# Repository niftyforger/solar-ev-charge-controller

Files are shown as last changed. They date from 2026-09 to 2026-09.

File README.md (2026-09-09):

# Solar EV Charge Controller

Diverts surplus rooftop solar into EV charging by dynamically limiting the charge current a "dumb" (non-networked) EVSE offers to the car, based on real-time export data from a Sungrow hybrid inverter. The EVSE has no API or Modbus control path, so the only lever available is intercepting its Control Pilot (CP) signal to the car and clipping the duty cycle down when there isn't enough solar surplus to support the current it would otherwise offer.

> **⚠️ Safety & Disclaimer**
> This project modifies wiring in a vehicle charging circuit, adjacent to mains-connected equipment. Incorrect wiring or assembly can cause electric shock, fire, or damage to your vehicle or EVSE. It is not a certified product, has not been evaluated by any safety body, and may void your EVSE's warranty. Build and use it entirely at your own risk — see the [Safety model](#safety-model) section below for the fail-safe design rationale, and the [LICENSE](LICENSE) for the "AS IS" warranty disclaimer.

For full pin assignments, register maps, timing/ISR design detail, and the fail-safe rationale, see [CLAUDE.md](CLAUDE.md).

## How it works

A single ESP32-S3 splits the job across its two cores: Core 0 polls the inverter over WiFi and decides a target amps — a ceiling offered via CP, not what the car necessarily draws; Core 1 runs the real-time loop that actually shapes the CP waveform between the charger and the car. The two talk over a small queue/mutex bridge — Core 1 never blocks on anything Core 0-side.

```mermaid
flowchart LR
    subgraph inv["Sungrow SH8.0RS"]
        meter["DTSU666-20 meter\n(RS485, internal)"]
        winet["WiNet-S\nModbus TCP :502"]
    end

    subgraph esp["ESP32-S3"]
        direction TB
        core0["Core 0\nWiFi + Modbus poll\nsettling control law\nBLE config · OTA · control page"]
        bridge[["shared_state\nqueue + mutex"]]
        core1["Core 1\nGPIO edge ISR + HW timer\n-> RMT clamp waveform"]
        core0 -- "target amps" --> bridge --> core1
    end

    subgraph cp["CP interceptor board"]
        sense["opto-isolated\nsense out"]
        clamp["clamp MOSFET\n(shunts CP_LINE toward GND only)"]
        relay["disconnect relay\n(NC, series on CP_LINE)"]
    end

    ble["BLE config client\n(phone/laptop)"]

    winet <-->|"Modbus TCP\nregister 13009"| core0
    meter --- winet
    ble <-->|"WiFi SSID/password,\ninverter IP, device IP"| core0
    core1 -->|"opto-isolated\ndrive"| clamp
    core1 -->|"opto-isolated\ndrive"| relay
    sense -->|"opto-isolated"| core1

    evse["EVSE\n(native CP driver)"] == "CP_LINE" ==> tap(("•"))
    tap == "CP_LINE" ==> relay
    relay == "CP_LINE, opens to isolate\nthe vehicle on demand" ==> vehicle["Vehicle"]
    tap -.->|"tap"| sense
    clamp -.->|"tap"| tap
```

Key properties baked into the topology, not just firmware:
- **`CP_LINE` runs straight through from the EVSE to the vehicle connector, only ever interrupted by the disconnect relay.** The interceptor board taps onto it at one point (upstream of the relay) to sense it and, when needed, shunt it low — the sense/clamp tap is never wired inline, so removing or failing the board there can't interrupt the wire itself. The relay is the one deliberate exception: it's wired inline, in series, specifically so it *can* interrupt the wire — see [Safety model](#safety-model) for why that's still fail-safe.
- The clamp can only **shunt `CP_LINE` toward `GND`** — it has no way to source voltage, so it can clip current down but can never raise it above what the EVSE natively offers, regardless of what firmware does.
- The relay only ever **removes the vehicle's CP termination**, never alters the waveform — with it open, the EVSE sees the same thing it would see on a real unplug (state A) and stops offering charge using its own normal handling, not a signal this project invents.
- Isolation is **signal-only**: the sense/clamp/relay lines that cross into/out of Core 1 each go through their own optocoupler, but the sense/clamp/relay circuitry itself shares a ground with the ESP32 side (no separate PE-referenced supply). See [CP interceptor circuit](#cp-interceptor-circuit) below.
- **Home-battery discharge doesn't count as surplus.** The meter sits downstream of the home battery, so it can't tell fresh PV export apart from battery-discharge export on its own — Core 0 reads the inverter's battery-power register separately and subtracts any discharge back out before computing how much current the surplus can support, so the loop never diverts battery power into EV charging.

See [Safety model](#safety-model) below for the full fail-safe contract.

## CP interceptor circuit

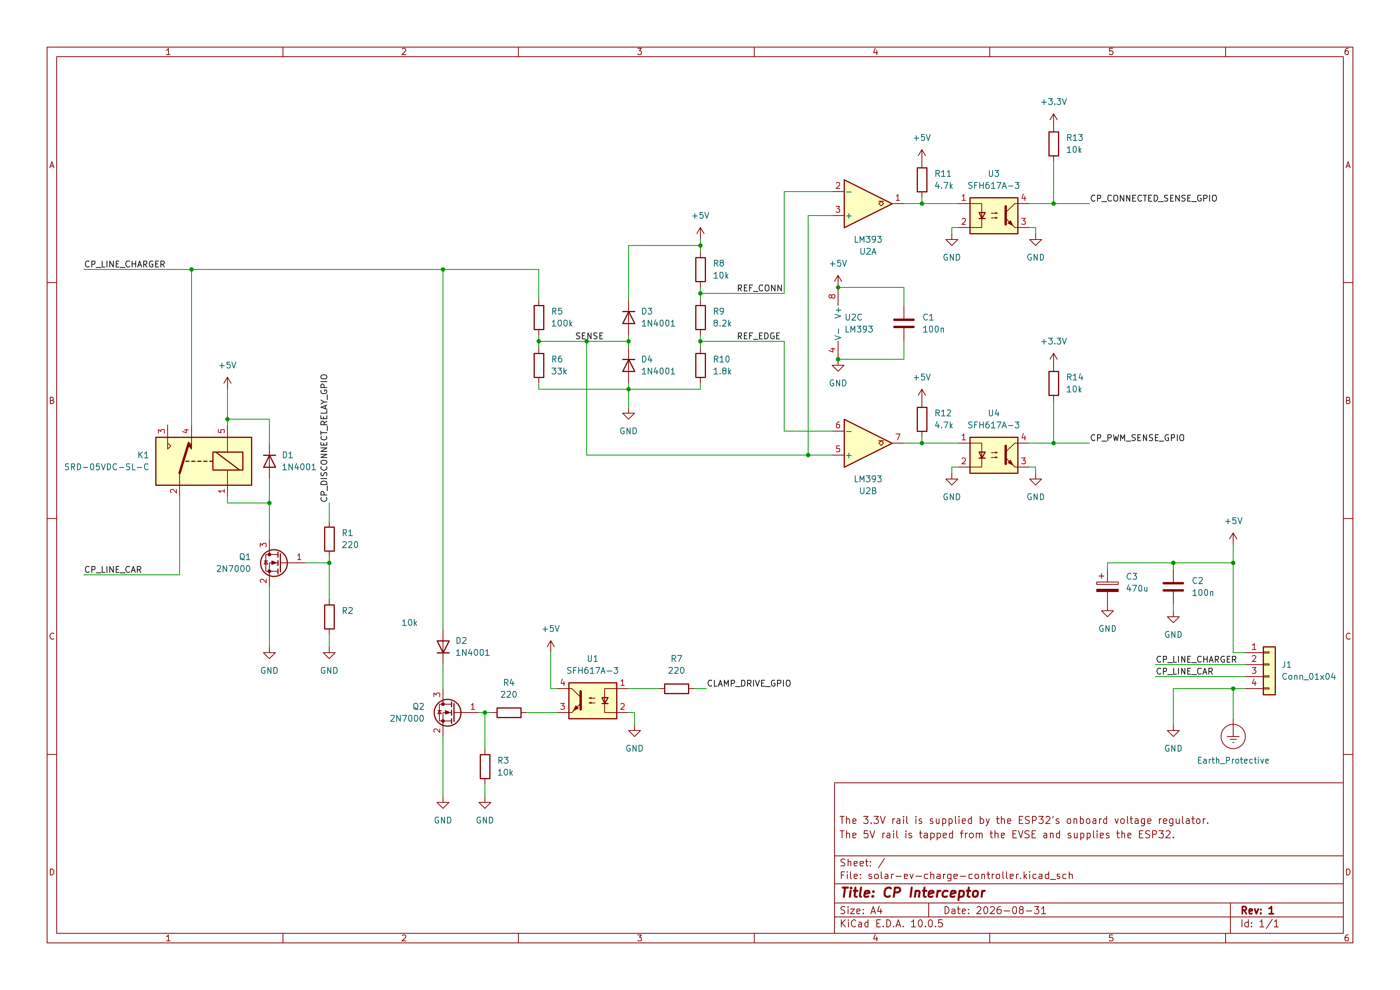
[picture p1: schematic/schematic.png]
CP interceptor schematic


KiCad source: [`schematic/solar-ev-charge-controller/`](schematic/solar-ev-charge-controller/).

`CP_LINE` feeds a high-Z divider (`R5`/`R6`) down to a `SENSE` node, read by a dual comparator (`U2`, LM393) against two fixed reference taps — one output detects vehicle-connected state (`CONNECTED_IN`), the other detects PWM edge activity (`EDGE_IN`). Each comparator output, plus the clamp drive command going the other way, crosses into the ESP32's domain through its own optocoupler (`U3`/`U4`/`U1` respectively) — that's the only isolation boundary; the sense/comparator/clamp circuitry otherwise shares `GND`/`+5V` with the ESP32 side. The clamp itself is a MOSFET (`Q2`, 2N7000) that taps onto `CP_LINE` through a series blocking diode (`D2`) and shunts it toward `GND` when driven; its gate defaults low via a pull-down resistor (`R3`) whenever nothing is actively driving it.

Further downstream (toward the vehicle) of the `R5`/`D2` tap sits a normally-closed disconnect relay (`K1`), wired in series on `CP_LINE` itself rather than tapped off it — the one deliberate break in an otherwise continuous wire. Its coil is driven through its own optocoupler and a low-side driver transistor (`Q1`), with a flyback diode (`D1`) across the coil. De-energized (the default whenever nothing is actively driving it) the contact stays closed and `CP_LINE` passes straight through; energizing it opens the contact and isolates the vehicle's CP termination from everything upstream, which the EVSE reads as a real unplug.

**Reference designators were renumbered by a KiCad annotation pass; the table below reflects the current schematic, wire-traced pin-by-pin to confirm.**

| Ref | Part | Note |
|---|---|---|
| `R5` / `R6` | 100kΩ / 33kΩ | `CP_LINE` → `SENSE` divider |
| `D3` / `D4` | 1N4001 | `SENSE` overvoltage clamp to `+5V` / `GND` |
| `R8` / `R9` / `R10` | 10k / 8.2k / 1.8k | reference ladder off `+5V` (REF_CONN ≈2.5V, REF_EDGE ≈0.45V) |
| `U2` | LM393 | dual comparator — unit 1 → `CONNECTED_IN` chain, unit 2 → `EDGE_IN` chain |
| `R11` / `R12` | 4.7kΩ | comparator unit 1/2 output pull-up to `+5V`, doubles as opto LED drive |
| `U3` / `U4` | SFH617A-3 | `CONNECTED_IN` / `EDGE_IN` optocouplers |
| `R13` / `R14` | 10kΩ | `CONNECTED_IN` / `EDGE_IN` pull-up to `+3.3V` (opto secondary) |
| `R7` | 220Ω | `CLAMP_DRIVE` opto (`U1`) LED current limit |
| `U1` | SFH617A-3 | `CLAMP_DRIVE` optocoupler |
| `R4` | 220Ω | opto secondary → `Q2` gate series resistor |
| `R3` | 10kΩ | `Q2` gate pull-down (default off) |
| `Q2` | 2N7000 | clamp MOSFET |
| `D2` | 1N4001 | series blocking diode, `CP_LINE` → `Q2` |
| `K1` | 5V SPDT signal relay (NC contact used) | disconnect relay, in series on `CP_LINE` downstream of the `R5`/`D2` tap |
| `Q1` | 2N7000 | `K1` coil low-side driver transistor |
| `D1` | 1N4001 | `K1` coil flyback diode |

Values are a starting point, not final — see [CLAUDE.md § CP interception circuit](CLAUDE.md#cp-interception-circuit) for the full rationale and [§ Open questions](CLAUDE.md#open-questions-for-implementation) for what's still unverified on the bench.

## Hardware

Freenove ESP32-S3-WROOM on its breakout board. Dual-core split:

| Core | Role |
|---|---|
| Core 0 | WiFi, Modbus TCP polling of the inverter, control law, BLE config server, OTA, control page |
| Core 1 (pinned, high priority) | GPIO edge-triggered ISR + hardware timer + RMT — asserts/releases the CP clamp with sub-task-switch latency |

Pin assignments live in [`include/config.h`](include/config.h) (see CLAUDE.md for the full table and rationale) — physically confirmed on the bench.

## Firmware layout

| File | Responsibility |
|---|---|
| [`src/main.cpp`](src/main.cpp) | Task/core setup |
| [`src/solar_control.*`](src/solar_control.cpp) | Core 0: WiFi, poll loop, settling control law, OTA, control page |
| [`src/modbus_tcp_client.*`](src/modbus_tcp_client.cpp) | Minimal hand-rolled Modbus TCP client for the WiNet-S |
| [`src/cp_interceptor.*`](src/cp_interceptor.cpp) | Core 1: edge capture, RMT clamp waveform, `BYPASS`/`ACTIVE` × `OSCILLATING`/`STANDBY` state machine, watchdog |
| [`src/shared_state.*`](src/shared_state.cpp) | Core0↔Core1 bridge (queue + mutex, zero-timeout on Core 1's side); also holds the BLE-provisioned WiFi/inverter-IP `RuntimeConfig` |
| [`src/ble_config.*`](src/ble_config.cpp) | Core 0: BLE server for provisioning WiFi SSID/password, inverter IP, and the BLE-config/control-page passwords, and reading back the device's current IP |
| [`include/config.h`](include/config.h) | Pins, control-loop constants, thresholds |
| [`include/secrets.h`](include/secrets.h) (gitignored) | `OTA_PASSWORD` only, used solely for OTA flashing — auto-generated from `.env` before every build, see below |

## Building & flashing

PlatformIO project, environment `freenove_esp32_s3_wroom`, framework Arduino.

```sh
cp .env.example .env   # then edit with a real OTA password
pio run                # build - regenerates include/secrets.h from .env first
pio run -t upload      # flash over USB
```

`include/secrets.h` is auto-generated from `OTA_PASSWORD` in `.env` by [`tools/sync_secrets.py`](tools/sync_secrets.py) (wired in as a PlatformIO pre-build step, so it runs for any env, any invocation path, including the VSCode PlatformIO IDE buttons) — don't edit it by hand, edit `.env` instead. WiFi SSID/password, the inverter IP, and the BLE-config/control-page passwords have no compile-time fallback — `OTA_PASSWORD` is used solely for OTA flashing. Everything else is provisioned over Bluetooth Low Energy after first flash. Connect with any BLE serial-terminal app (Serial Bluetooth Terminal, nRF Connect's UART plugin, etc.) — it auto-detects the device as a Nordic UART Service and drops straight into terminal mode — then send `AUTH <anything>` (open until a `BLE_PASS` is set), `SET WIFI_SSID <ssid>`, `SET WIFI_PASS <password>`, `SET INVERTER_IP <inverter ip>`, `COMMIT`, `SET BLE_PASS <password>` (required for `AUTH` on future connections), and `SET WEB_PASS <password>` (required before the HTTP control page below will respond to anything but a 403) — send `HELP` any time for the full command list. See [CLAUDE.md § BLE configuration](CLAUDE.md#ble-configuration) for the full protocol.

BLE advertises **indefinitely** until the device has been provisioned at least once, so a freshly-flashed board is always reachable — after that first `COMMIT`, it only advertises for `BLE_ADVERTISE_WINDOW_MS` (5 minutes, [`include/config.h`](include/config.h)) after each boot, closing the window for the rest of that session. To reconfigure a device that's already provisioned, power-cycle it and connect within that 5-minute window.

Once WiFi is up, subsequent flashes can go over OTA (`ArduinoOTA`, password-protected by `OTA_PASSWORD`) instead of pulling the board for USB access. Run it with `python tools/ota_upload.py` (loads `.env`'s `UPLOAD_PORT`/`OTA_PASSWORD` for that one invocation), or run `python tools/sync_env_vars.py` once and restart VSCode to make the PlatformIO IDE's own "Upload" button work directly with the `ota` environment selected — see the `[env:ota]` comment in [`platformio.ini`](platformio.ini) for why `.env` can't be wired in more automatically than that. The control page at `http://<device-ip>/` (HTTP Basic Auth, username `admin`, password set over BLE via `SET WEB_PASS` — refuses all requests until one has been set) is the same page used for live operation, with a grid-source dropdown to switch between the real inverter and a family of reactive simulated scenarios (no sun / low / moderate / high / battery-discharge) — the latter exercise the full poll/control-law/target-amps path for bench and night-time testing without real solar.

## Safety model

- **Inherent (topology-level):** no drive on `CLAMP_DRIVE` (idle, unpowered, firmware not yet running) → a pull-down resistor holds the clamp MOSFET's gate low → native pass-through, unconditionally. Clamp stuck on/shorted → CP read as a fault/disconnect by the EVSE → charging stops, doesn't misbehave. The clamp can never drive current *above* native regardless of firmware state, since it can only shunt the line toward `GND`, never source voltage onto it. The disconnect relay (`K1`) follows the same direction: no drive on its coil → normally-closed contact stays closed → `CP_LINE` passes through unconditionally. Losing the ESP32 must never leave the vehicle unable to charge at all.
- **Explicit (firmware-level):** if Core 0 can't get a fresh inverter reading for ~60s, Core 1 switches to `MODE_BYPASS`, stops scheduling clamp assertions, and keeps the disconnect relay closed regardless of duty state — same end state as a power loss. A data fault is never treated as a confident "no surplus" decision, so it never triggers a disconnect. A hardware watchdog on the CP task forces a reboot rather than letting a hang freeze the waveform mid-cycle.
- **When surplus is genuinely below the 6A floor** (fresh data, not a fault): Core 1 opens `K1`, isolating the vehicle's CP termination so the EVSE reads a real unplug and stops charging via its own handling — this *is* a relay-backed physical disconnect, and deliberately replaced an earlier version that instead released the clamp to full native current at exactly the moment surplus was lowest. See [CLAUDE.md § CP interception circuit](CLAUDE.md#cp-interception-circuit) for the full rationale.

## Status

Bench-tested through all stages, including the real EVSE and a real vehicle (2026-09-04): BLE provisioning, comparator thresholds, disconnect-relay open/close, and live mid-charge duty-cycle changes all confirmed clean. All previously open items are now resolved — see [CLAUDE.md § Open questions](CLAUDE.md#open-questions-for-implementation).

## Gallery

Control page:

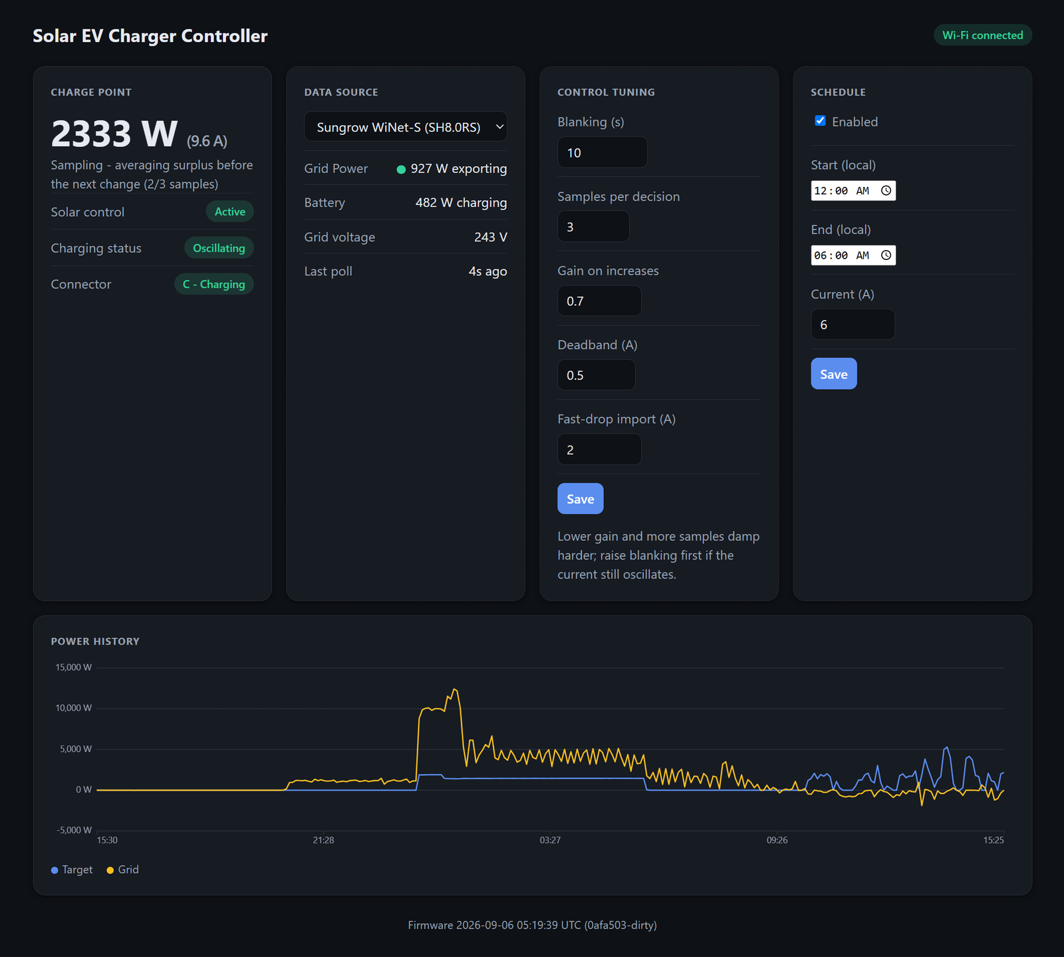
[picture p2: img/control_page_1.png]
Control page 1


Bench setup:

| | |
|---|---|
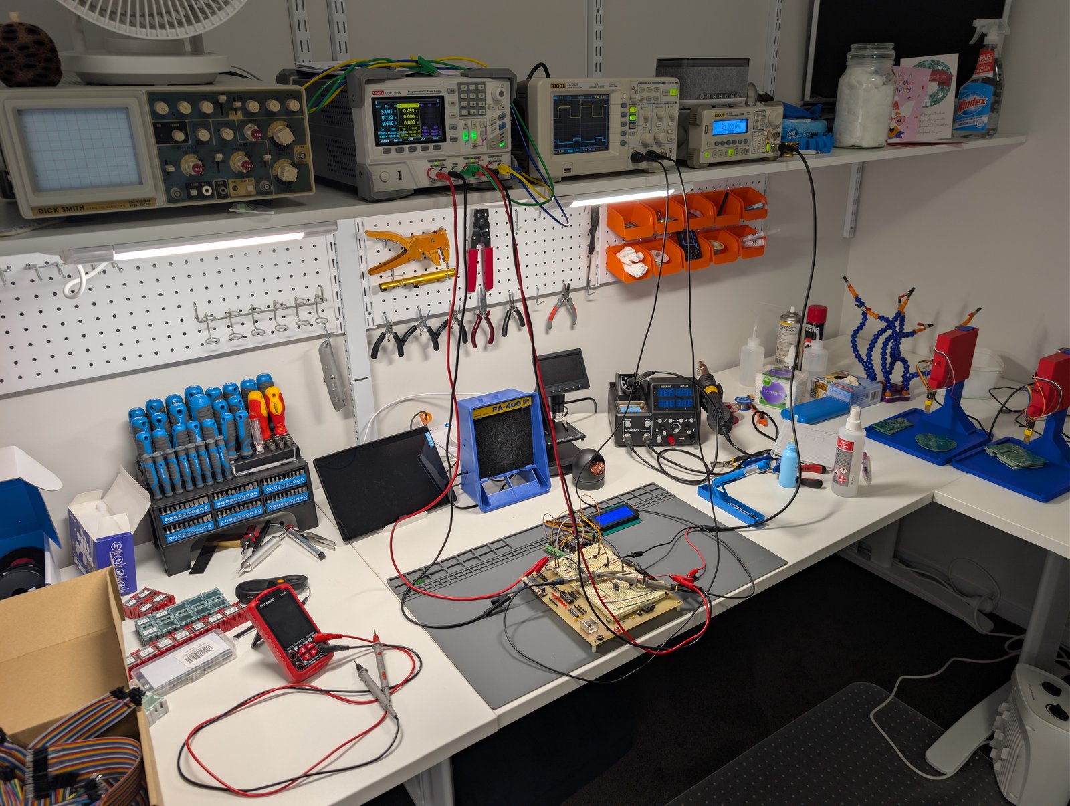
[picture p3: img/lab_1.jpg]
Bench setup 1
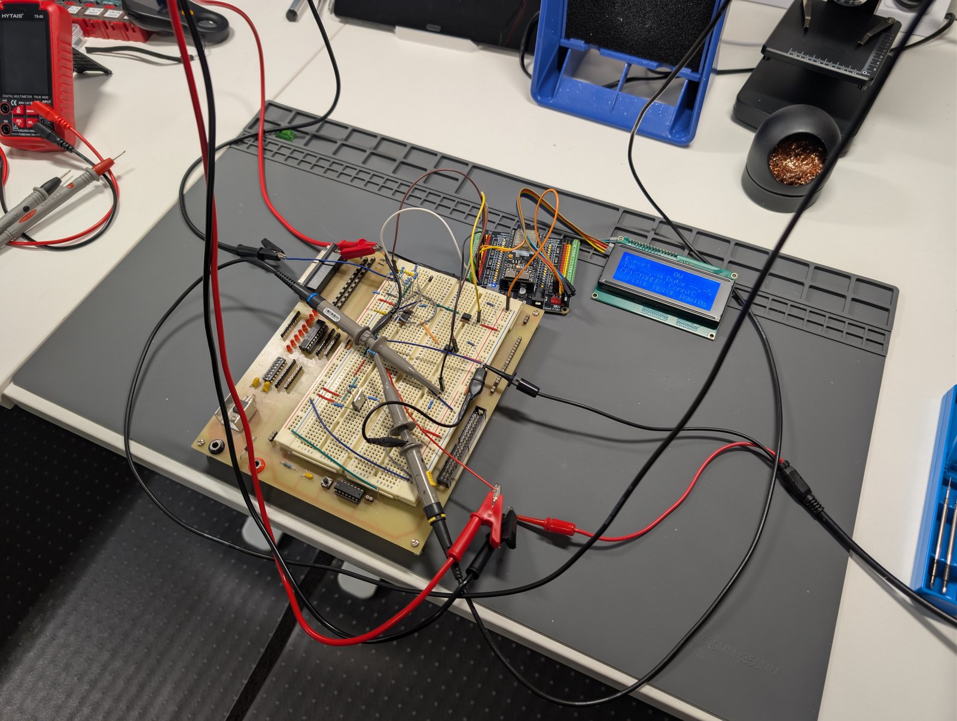
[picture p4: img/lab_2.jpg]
Bench setup 2
|  |  |
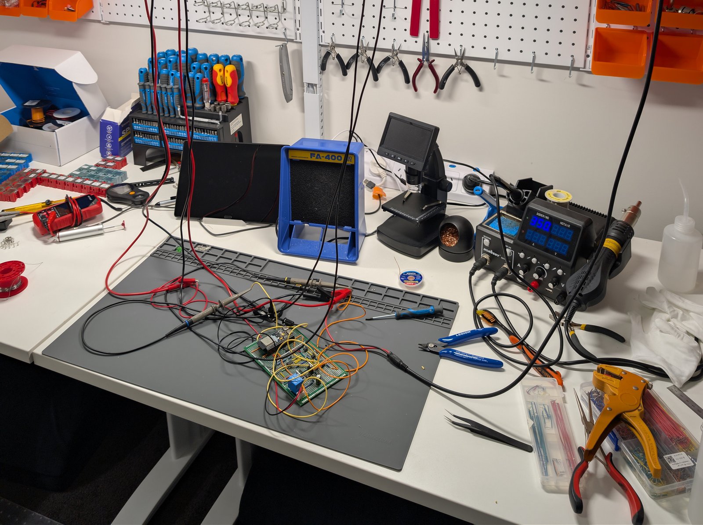
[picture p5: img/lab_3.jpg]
Bench setup 3
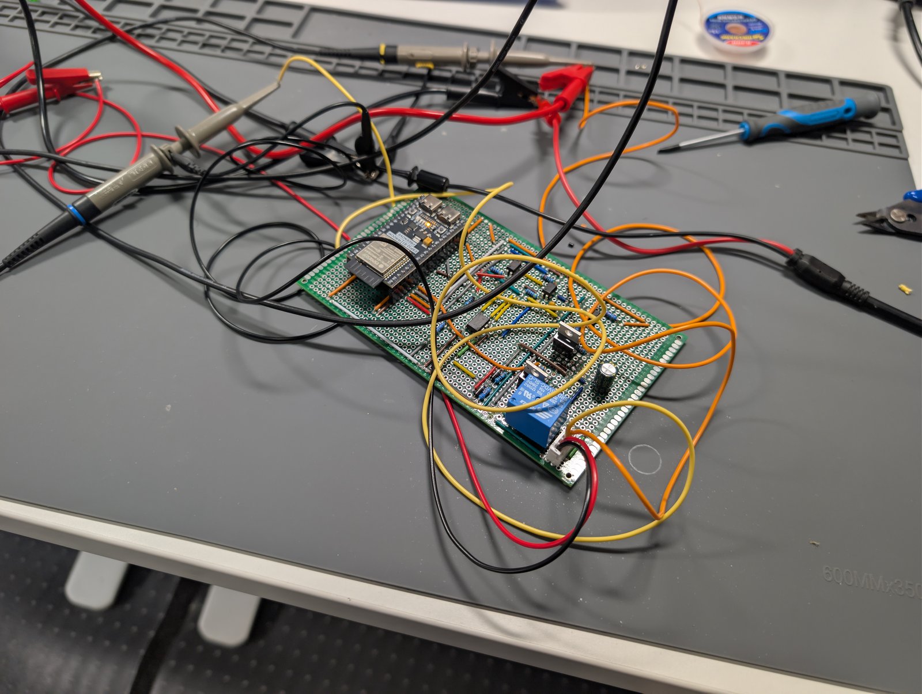
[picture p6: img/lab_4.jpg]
Bench setup 4
|  |  |

EVSE enclosure:

| | |
|---|---|
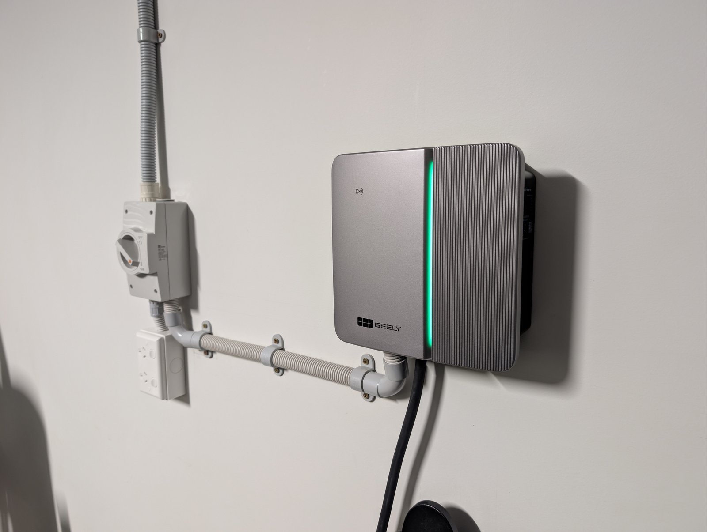
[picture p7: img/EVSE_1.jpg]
Control board installed inside the EVSE enclosure
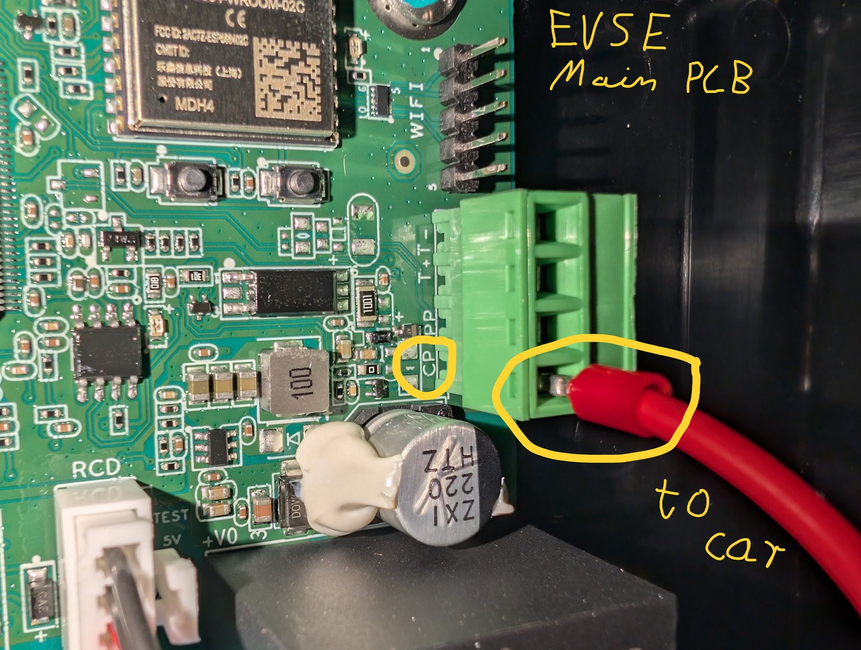
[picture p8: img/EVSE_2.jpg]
Control board installed inside the EVSE enclosure
|  |  |
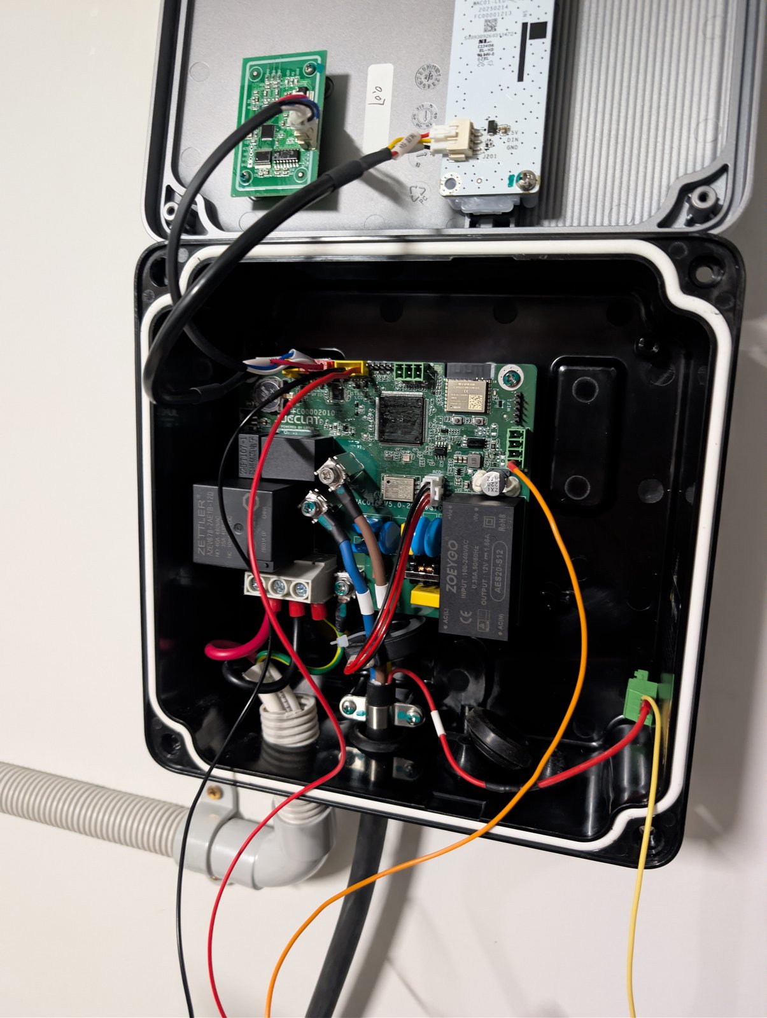
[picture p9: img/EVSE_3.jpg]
Control board installed inside the EVSE enclosure
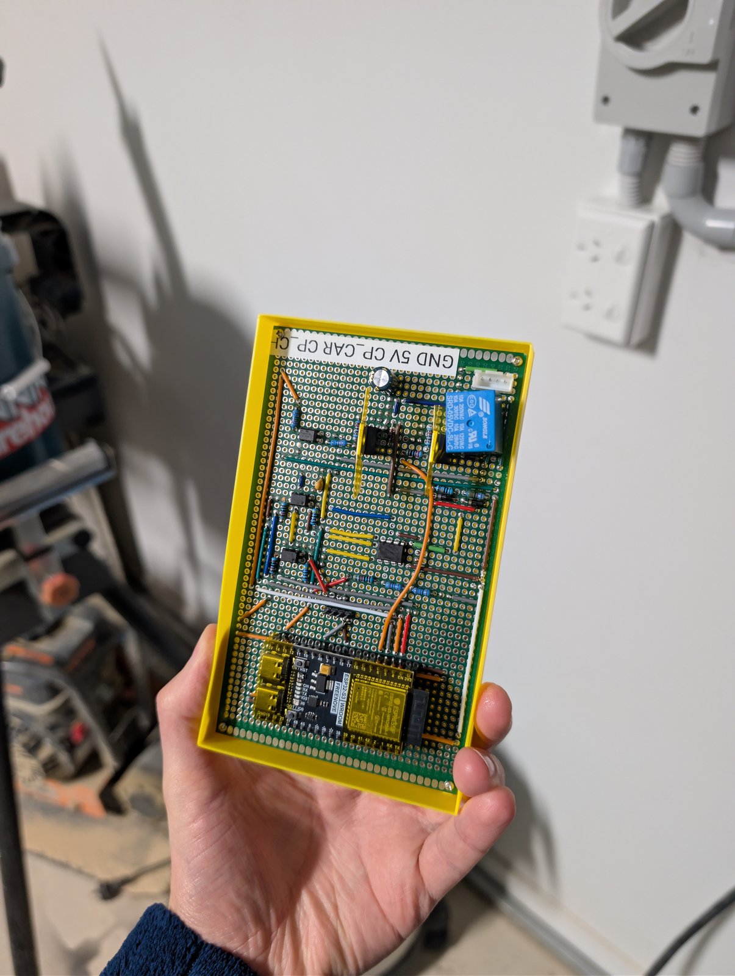
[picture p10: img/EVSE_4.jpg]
Interceptor board in its 3D-printed enclosure
|  |  |
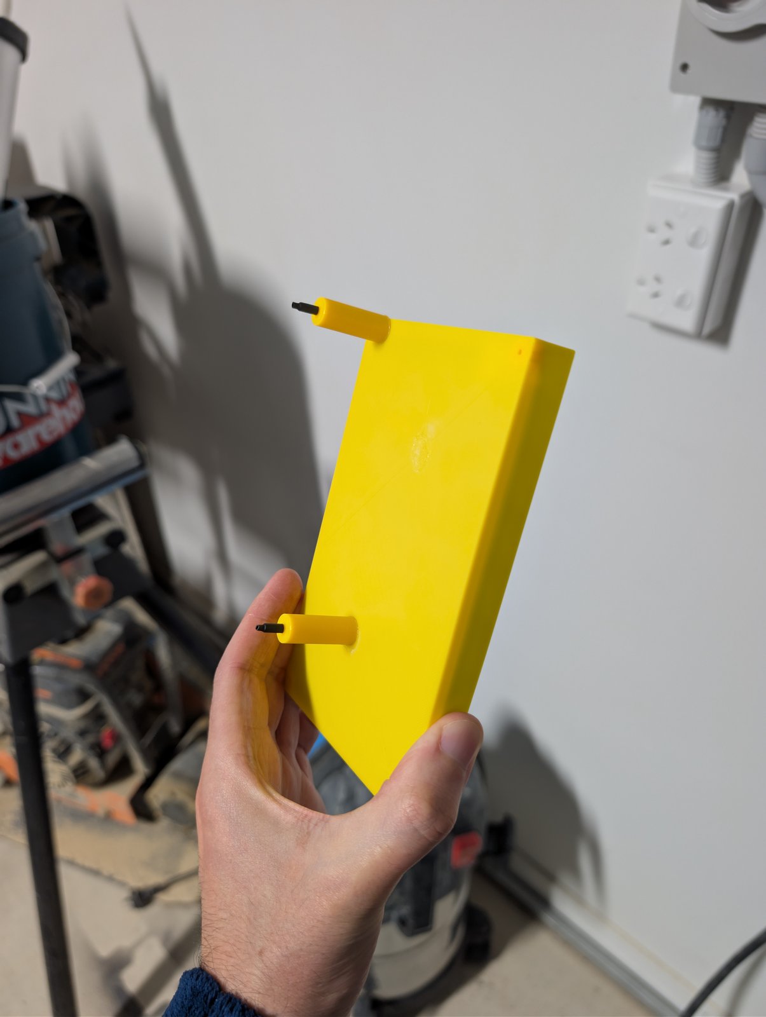
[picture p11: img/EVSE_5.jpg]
Interceptor enclosure, closed
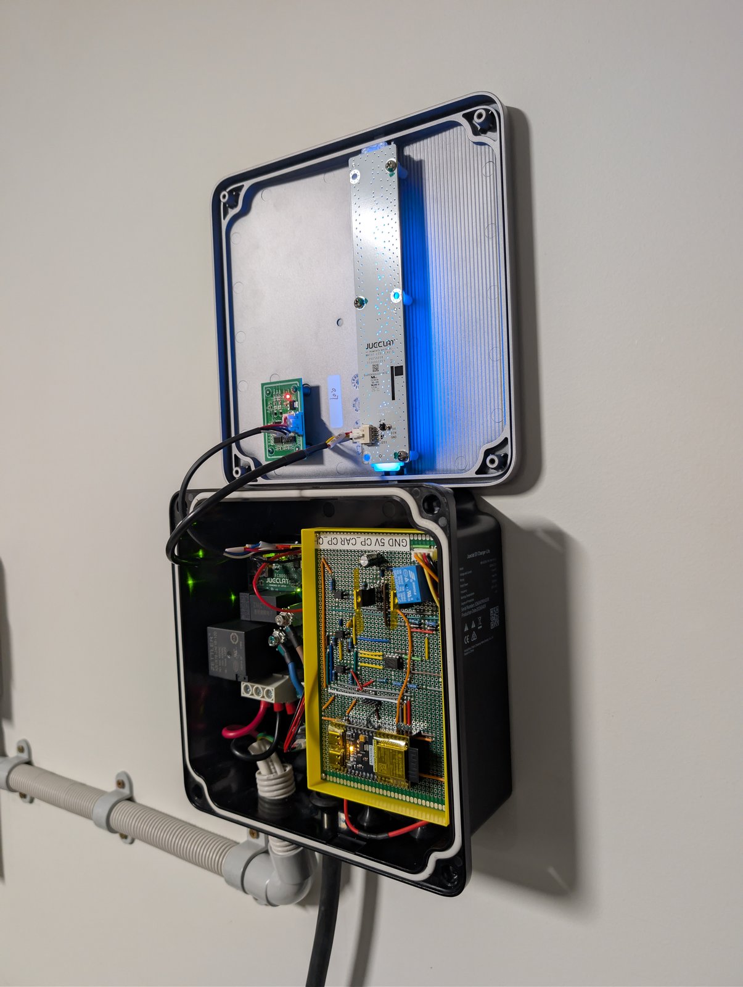
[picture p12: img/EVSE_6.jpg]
Interceptor board mounted inside the powered-on EVSE
|  |  |

## Author

[coder@niftyforger.com](mailto:coder@niftyforger.com)

Need a better way to organize your inventory, assemblies and projects? Try [niftyforger.com](https://niftyforger.com)

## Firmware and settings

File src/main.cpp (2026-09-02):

#include <Arduino.h>
#include "config.h"
#include "shared_state.h"
#include "solar_control.h"
#include "ble_config.h"
#include "cp_interceptor.h"

void setup() {
    Serial.begin(115200);

    shared_state_init();

    // BLE config server: independent of WiFi state, must come up even on a
    // fully unprovisioned board - see ble_config.cpp.
    ble_config_init();

    // Core 1: real-time CP interception, pinned + highest priority.
    xTaskCreatePinnedToCore(cp_interceptor_task, "cp_interceptor", 8192,
                             nullptr, TASK_PRIO_CP, nullptr, CORE_CP);

    // Core 0: WiFi/Modbus control loop.
    xTaskCreatePinnedToCore(solar_control_task, "solar_control", 8192,
                             nullptr, TASK_PRIO_SOLAR, nullptr, CORE_SOLAR);
}

void loop() {
    vTaskDelete(NULL);
}

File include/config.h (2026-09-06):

#pragma once

#include <stdint.h>

// Pin assignments. ESP32-S3: ADC1 = GPIO1-10 (ADC2 shares hardware with WiFi, avoid it).
// Strapping pins (0, 3, 45, 46) and USB-JTAG pins (19, 20) are avoided.

// CP sense input (post opto-isolator, digital 0/3.3V square wave)
#define CP_PWM_SENSE_GPIO      5

// CP clamp drive output -> optocoupler -> MOSFET gate driver (RMT TX)
#define CLAMP_DRIVE_GPIO       6

// CP connector-state sense, CONNECTED_IN (post opto) - see CLAUDE.md "CP interception circuit"
#define CP_CONNECTED_SENSE_GPIO 4

// CP disconnect relay drive -> opto -> coil driver. NC relay in series on CP_LINE;
// energizing opens it (EVSE reads state A). De-energized/no-drive = closed = pass-through.
#define CP_DISCONNECT_RELAY_GPIO 7

// CP electrical / protocol constants (IEC 61851-1 / SAE J1772 §6.4)
#define CP_MIN_DUTY_PCT         10.0f
#define CP_MAX_DUTY_PCT         96.0f
#define CP_DUTY_PCT_PER_AMP     (1.0f / 0.6f)   // duty% = amps / 0.6

#define MIN_CURRENT_A            6.0f
#define MAX_CURRENT_A            32.0f

// Grid voltage is per-GridDataSource (see grid_data_source.h); this is the fixed value
// simulated sources report and grid_source_sungrow_winet.cpp's fallback before its
// first successful voltage-register read.
#define MAINS_VOLTAGE_FIXED_V    240.0f

// Native PWM sanity window (~1kHz nominal, generous guard band against glitches)
#define NATIVE_PERIOD_MIN_US     800.0
#define NATIVE_PERIOD_MAX_US     1300.0

// Only arm the clamp if it shortens the pulse by at least this much - avoids relay/MOSFET/RMT churn for no effect.
#define MIN_CLAMP_MARGIN_PCT     0.5f

// Compensates the rising-edge-ISR -> hardware-timer -> RMT-assert dispatch latency (see
// assert_timer_isr() in cp_interceptor.cpp). Bench-measured (5.7us, single sample at 10%
// duty); re-derive with a scope if the ISR path is ever rewritten.
#define CLAMP_DISPATCH_LATENCY_US   5.7

// Exit-from-OSCILLATING margin below MIN_CURRENT_A, to stop noise at the floor from
// flapping the clamp. Entry uses the bare floor, no margin (10% duty is a fully valid
// signal). Confirmed adequate against the real vehicle, 2026-09-04.
#define HYSTERESIS_A             1.0f

// Minimum hold time for the CP_STANDBY/CP_OSCILLATING duty state (and therefore the
// disconnect relay) before it can flip again, on top of HYSTERESIS_A - bounds relay
// cycle life and gives the EVSE/vehicle time to complete an unplug/replug handshake.
// Confirmed adequate against the real vehicle, 2026-09-04.
#define RELAY_MIN_DWELL_MS       10000UL

// Connector-state discrimination: one CONNECTED_IN threshold (REF_CONN, A vs B) and one
// EDGE_IN threshold (REF_EDGE, D vs E) give four buckets, not six - A; B; C incl. D
// (toggling); FAULT incl. E/F (steady-low). D is unused on this install and E/F both
// already mean "don't clamp", so the conflation costs status granularity only. See
// read_connector_state() in cp_interceptor.cpp and CLAUDE.md "CP interception circuit".
//
// How long since the last rising edge before read_connector_state() calls the line "not
// oscillating" - sized above NATIVE_PERIOD_MAX_US to tolerate jitter, well below
// CP_STATUS_PUBLISH_MS so a real stop shows up promptly.
#define CP_ACTIVITY_TIMEOUT_US   3000

// RMT (legacy driver/rmt.h - ESP-IDF 4.4 bundled with this platform version)
#define CP_RMT_TX_CHANNEL        RMT_CHANNEL_0
#define RMT_CLK_DIV              8       // 80MHz APB / 8 = 10MHz -> 0.1us/tick

// Core 1 CP task timing. cp_interceptor_task's planning loop is not on the timing-critical
// path - cp_sense_isr() applies the clamp plan directly on each rising edge.
#define CP_NOTIFY_WAIT_MS         100
#define CP_STALE_CHECK_MS         1000
#define CP_STATUS_PUBLISH_MS      200
#define CP_TASK_WDT_TIMEOUT_MS    3000

// Separate recovery watchdog for solar_control_task, checked by Core 1 (see
// shared_state_heartbeat_solar_task()). Kept independent of CP_TASK_WDT_TIMEOUT_MS
// because solar_control_task legitimately blocks much longer than 3s during an
// ArduinoOTA push - sized comfortably above any expected OTA duration.
#define SOLAR_TASK_HEARTBEAT_TIMEOUT_MS 120000UL

// Core 0 solar control loop
#define POLL_INTERVAL_MS          5000UL
#define STALE_DATA_TIMEOUT_MS     60000UL
#define WIFI_RECONNECT_INTERVAL_MS 5000UL
#define WIFI_HOSTNAME              "solar-ev-charger"

// Control-loop damping against measurement lag (see CLAUDE.md "Control-loop damping").
// These are compile-time DEFAULTS only - all five are runtime-tunable from the HTTP
// control page and persisted in the "control" NVS namespace (see ControlTuning in
// solar_control.cpp), because the right values depend on this install's actual inverter
// and vehicle lag, which can only be measured against real weather.
//
// Together they replaced the old single SETTLE_MS window, which gated reaction rate but
// filtered nothing: one instantaneous sample drove a full-magnitude correction.
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

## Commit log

2026-08-23 Initial project skeleton and CP interceptor
    Add complete PlatformIO project scaffold for geely-charger-controller: platformio.ini, config headers, secrets.example, example LCD sketch, and documentation. Implement core firmware components: CP interceptor (Core1) with GPIO edge capture + RMT clamp, solar_control (Core0) WiFi + Modbus TCP client reading register 13009, shared_state bridge, and status_display task. Includes minimal Modbus TCP helper, ADC/ADC1 pin config, and fail-safe/bypass logic. Hardware assumptions and tuning placeholders remain (bench validation required).
    [config.h, cp_interceptor.cpp, main.cpp]
2026-08-23 Fix Sungrow read order and WiFi hostname
    This commit corrects the Sungrow SH8.0RS 13009 register decoding to use the actual low-word-first 32-bit layout returned by the WiNet-S, eliminating bogus export/import values. It also sets a stable WiFi hostname so the controller is easier to identify on the network during bring-up and debugging.
    [config.h]
2026-08-23 Normalize grid-power polarity and add logging
    Detect and compensate for the Sungrow/WiNet-S quirk where REG_GRID_POWER's native sign is inverted. modbus_read_grid_power_w() now composes the S32 little-endian value, negates it so callers see negative=exporting, and emits a Serial.printf debug line showing raw regs and interpreted direction. Updated comments in include/config.h and src/modbus_tcp_client.h and documented the behavior in CLAUDE.md.
    [config.h]
2026-08-24 Add OTA and simulation web UI; integrate sim mode
    Adds OTA support and a password-protected simulation web UI to toggle between real Modbus reads and a synthetic grid-power value. solar_control now starts ArduinoOTA and a WebServer, serves / and /se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
2026-08-24 Expose control decisions to web UI
    Introduce a ControlDecision enum and decision_reason_str, and change compute_next_target_amps to return a decision while emitting the new target via an out parameter. Cache recent solar/control state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
2026-08-24 Update mains voltage calibration
    Raise the configured mains voltage from 230V to 240V to match the actual nominal supply and keep derived current/power calculations aligned with the installation.
2026-08-24 Refactor CP interceptor: ISR/timer, LL, watchdog
    Rewrite CP interceptor timing to use a hardware timer alarm + IRAM ISR and register-level (hal/*_ll.h) RMT writes so clamp scheduling runs with minimal jitter and no flash-resident driver calls. Remove the edge queue and change to a task (planning) → ISR (execution) handoff using Core-1-local volatile tick params. Add CLAMP_DISPATCH_LATENCY_US and SOLAR_TASK_HEARTBEAT_TIMEOUT_MS to config and recalibrate latency comments. Add a Core-0 heartbeat (shared_state) so Core-1 can detect a wedged solar task and restart the system. Fix ArduinoOTA/WebServer lifecycle by separating network callback registration from per-reconnect binding. Update docs (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
    [config.h, cp_interceptor.cpp]
2026-08-25 Add CCS2_charge_limiter KiCad schematic
    Add full KiCad schematic/project for CCS2_charge_limiter (CCS2_charge_limiter.kicad_sch, .kicad_pcb, .kicad_prl, .kicad_pro) and schematic PNG. Update .gitignore to exclude /schematic/CCS2_charge_lim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
    [CCS2_charge_limiter.kicad_pcb, CCS2_charge_limiter.kicad_sch]
2026-08-25 Refactor CP interceptor docs & code; add README
    Add a top-level README and substantially update the CLAUDE.md reference. Switch CP sensing from an ADC-based approach to a comparator/opto digital scheme: introduce CP_CONNECTED_SENSE_GPIO, add CP_ACTIVITY_TIMEOUT_US, and remove the RELAY_K1 relay GPIO. Update include/config.h pin/comments and clarifications for the hardware topology and fail-safes. Update cp_interceptor.cpp to publish a 32-bit last-rise timestamp (s_lastRiseUs32), use digital GPIO reads instead of analogRead, remove relay control and ADC setup, and change read_connector_state() to use opto comparator outputs + edge recency. Minor shared_state.h enum comment tweak. Motivated by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
    [config.h, cp_interceptor.cpp]
2026-08-30 Update VSCode, docs, platformio and schematic
    Add VSCode extension recommendations (esp-decoder, pioarduino) and tidy extensions.json. Update CLAUDE.md with hand-verified CP sensing values and note tightening of resistor tolerances. Change PlatformIO OTA upload_port to 192.168.0.151. Mark three schematic resistor symbols with a 1% "Tolerance" property to reflect tightened R1/R2/R3 values and close the A/B threshold margin.
    [CCS2_charge_limiter.kicad_sch]
2026-08-30 Invert CP_CONNECTED_SENSE_GPIO polarity
    Bench-confirmed inversion of CP_CONNECTED_SENSE_GPIO (2026-08-30). Update CLAUDE.md and src/cp_interceptor.cpp to document the actual comparator/opto polarity and flip the read_connector_state() check so LOW now maps to CONN_STATE_A (no vehicle). CP_PWM_SENSE_GPIO behavior unchanged.
    [cp_interceptor.cpp]
2026-08-30 Fix CP sense polarity and clamp timing
    Bench-confirm and fix inverted CP sense polarity and related timing bugs. Update cp_interceptor.cpp: flip CP PWM sense checks so level==0 is the real rising edge, invert edge-idle logic in read_connector_state(), and compute assertTargetUs so holdUs is derived from the uncompensated target (avoids double-counting CLAMP_DISPATCH_LATENCY_US). Update CLAUDE.md to record the polarity discovery and the timing-fix rationale. This prevents clamping into the negative half-cycle and corrects hold-duration behavior.
    [cp_interceptor.cpp]
2026-08-31 Add CP disconnect relay and relay-control logic
    Introduce a normally-closed CP disconnect relay and firmware support so CP_STANDBY isolates the vehicle (opens relay) when surplus is genuinely below the 6A floor. MODE_BYPASS/stale-data keeps the relay closed. Added CP_DISCONNECT_RELAY_GPIO and RELAY_MIN_DWELL_MS to config.h, initialized and driven in cp_interceptor.cpp, with dwell-time guarding to avoid relay chatter. Updated docs (CLAUDE.md, README.md), KiCad schematic (kicad_pro/.kicad_sch and schematic.png), and UI strings (solar_control.cpp, status_display.cpp). Minor shared_state comments updated to reflect semantics.
    [CCS2_charge_limiter.kicad_sch]
2026-09-02 Remove unused status LCD (display.ino, status_display.cpp/h)
    GPIO 8/9 (formerly the LCD's I2C bus) are now free - see config.h.
2026-09-02 Add BLE provisioning, grid source & build tools
    Add a BLE NUS-based provisioning server (src/ble_config.cpp, include/ble_config.h) and runtime WiFi/inverter/config plumbing (shared_state RuntimeConfig + setters/getters). Introduce a grid-data abst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
    [solar-ev-charge-controller.kicad_pcb, solar-ev-charge-controller.kicad_sch]
2026-09-02 Pre-publish cleanup: fix schematic designators, add LICENSE
    - Correct reference designators in CLAUDE.md/README.md/config.h to
    match the actual schematic after a KiCad renumbering pass (verified
    by wire-tracing the .kicad_sch), including Q2's real part (2N7000,
    not AO3400).
    - Add MIT LICENSE.
    - Untrack KiCad auto-backup zips and .claude/.vscode local tooling
    config; gitignore them going forward.
    [config.h]
2026-09-02 Switch grid data source to Sungrow WiNet-S
    Replace the DTSU666-based grid-data backend with a Sungrow WiNet-S implementation. Added src/grid_source_sungrow_winet.cpp, removed src/grid_source_dtsu666.cpp, and updated src/grid_data_source.h and include/config.h to point ACTIVE_GRID_DATA_SOURCE at GRID_SOURCE_SUNGROW_WINET. CLAUDE.md was updated to document the Sungrow WiNet-S register handling (little-endian word order and inverted sign) and the new implementation. Behavior/logging of the Modbus read is preserved.
    [config.h, grid_source_sungrow_winet.cpp]
2026-09-02 Clarify CP safety model and OTA env flow
    This patch updates the project docs and inline code comments to better describe the CP interception design, STANDBY relay behavior, native pass-through fail-safes, and the IRAM/ISR timing constraints. It also clarifies the OTA upload setup: why PlatformIO upload env vars must come from the parent process, and how the env-sync scripts fit into the build flow. No functional control logic changes are included; this is documentation/commentary cleanup to match the tested hardware behavior.
    [config.h, cp_interceptor.cpp]
2026-09-02 Add runtime-selectable grid data source
    Introduce a runtime-selectable GridDataSource registry and plumbing. Add grid_data_source_registry.cpp and a stub implementation (fixed -500W) for testing, and extend grid_data_source.h with a stable id, registry, count, and lookup function that always falls back to index 0. Update sungrow source to provide an id. Wire selection into solar_control: load/save to NVS (namespace "gridsrc"), add web UI /set_source handler, and use the active source for reads. Also update docs and config comments to reflect the new runtime selection model.
    [config.h, grid_source_sungrow_winet.cpp]
2026-09-02 Persist Modbus TCP connection across polls
    ModbusTcpClient now holds a persistent WiFiClient and adds setHost() and ensureConnected() helpers so the socket is reused across polls and only reconnects on failure. readInputRegisters() uses the persistent client and no longer creates a transient WiFiClient per call. grid_source_sungrow_winet.cpp now uses a function-local static ModbusTcpClient and calls setHost(host) instead of constructing a new client each poll. CLAUDE.md updated to reflect the persistent-connection behavior and rationale (avoid stressing the WiNet-S gateway).
    [grid_source_sungrow_winet.cpp]
2026-09-02 Serve SPA and add JSON status API
    Replace server-side HTML rendering with a static single-page app served from PROGMEM and add a compact JSON status API. The large dynamic HTML buffer (s_page_body) was removed and a small s_json_body builder added; handlers now expose /api/status, /api/set and /api/set_source and root serves the SPA. Add helper label/class functions for connector state and an append_sources_json() helper. Reduces RAM/stack pressure, enables live client polling of runtime state, and keeps auth checks intact.
2026-09-02 Add simulated grid sources & runtime mains voltage
    Introduce two fixed simulated grid sources (export/import) and register them in the data-source registry; remove the old stub. Make mains voltage runtime-configurable and persisted to NVS (new MAINS_VOLTAGE_* constants, load/save helpers, UI + /api/set_voltage endpoint). Update web UI to expose mains voltage (remove legacy sim-toggle fields). Update compute_next_target_amps to use the runtime mains voltage and adjust status JSON. Update docs (CLAUDE.md) to reflect these changes.
    [config.h]
2026-09-03 Reactive grid sources and per-source voltage
    Replace fixed-value grid simulations with a reactive source family that models PV, house load, and the EV's own draw, so the control loop converges instead of endlessly climbing to MAX_CURRENT_A. Remove the per-poll step cap and compute target amps directly from the current surplus reading, while keeping `SETTLE_MS` as the rate gate. Add per-source voltage reporting, including a real Sungrow WiNet voltage read with a fallback to last-good voltage, and remove the old manual mains-voltage config from the HTTP UI and NVS flow. This makes the loop reflect actual closed-loop behavior and keeps the grid-source abstraction truly runtime-selectable.
    [config.h, grid_source_sungrow_winet.cpp]
2026-09-03 UI: Reorganize charge point and data source
    Refactor the web UI: relabel charge-point fields (Mode→Solar control, Clamp→Charging status), move the grid source selector into a new "Data source" card, and add an inline "Last poll failed" note. Remove the old Settings card that contained the source selector. Update JS to toggle the new poll-failed note instead of appending text to the source name. This cleans up the layout and surfaces poll-failure state more clearly.
2026-09-03 Add timed fixed-current charging
    Adds an NTP-backed schedule that can force a fixed charging current while a UTC time window is active, with the setting persisted in NVS and exposed in the web UI. The control loop ignores solar surplus during an active schedule window, while the CP interceptor keeps MODE_ACTIVE if either the grid poll or the schedule confirmation is fresh. This avoids stalling on a dead inverter path while still falling back to native pass-through when both are stale.
    [config.h, cp_interceptor.cpp]
2026-09-03 UI: show target power first on dashboard
    Swap the dashboard primary metric from amps to watts and reorder the target display so power (W) is shown first with current (A) as the subordinate value. Move the grid power/flow element into the source card and adjust render() to update the new element IDs/formatting. This improves clarity by surfacing instantaneous power as the primary control feedback and keeps the UI consistent with other status fields.
2026-09-04 Exclude home-battery discharge from surplus
    Add battery-power reporting and exclusion so the control loop won't treat home-battery discharge as solar surplus. Changes: extend GridDataSourceReadFn to return outBatteryW and expose battery fields in grid_data_source.h and the registry; add a simulated reactive battery-discharge source; update all reactive simulated sources to report zero battery power; add battery_power_w to shared_state and the HTTP status JSON/UI (battery_w, battery_state, surplus_excluded_w); and update solar_control to compute effectiveGridPowerW = gridPowerW + fmaxf(0.0f, -batteryPowerW) before deciding target amps.
    Sungrow WiNet implementation corrected battery register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
    [grid_source_sungrow_winet.cpp]
2026-09-04 Refactor docs; fix CP interceptor & grid sources
    Polish docs and comments (CLAUDE.md, README.md) and tighten config annotations. Fix multiple CP-interceptor issues: ISR polarity handling, latency compensation, RMT/timer IRAM path, clamp timing, and relay STANDBY behavior (now opens disconnect relay instead of releasing clamp). Improve cp_interceptor task handoff ordering and watchdog/stale-data logic. Correct Sungrow WiNet parsing (grid power word order/polarity, battery = S16), add voltage/battery fallbacks and sanity checks. Replace/clarify reactive simulated grid sources (including battery-discharge scenario). Small cleanups in BLE, shared_state, and solar_control (settling/floor/hysteres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
    [config.h, cp_interceptor.cpp]
2026-09-04 Resolve open implementation questions
    Document the final design decisions for the remaining implementation questions. This commit resolves the CP interception shared-ground design as the final choice and closes out the Sungrow 13021 battery-register scale question, noting the prior discrepancy was likely window skew rather than a real register error. The other open items are retained as completed record entries.
2026-09-04 UI: clarify Voltage label to 'Grid voltage'
    Change the control-page label from "Voltage" to "Grid voltage" in src/solar_control.cpp to make it clear the value refers to mains/grid voltage (not battery/PV). Pure UI text change, no functional im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
2026-09-04 Add safety disclaimer to README
    This change adds a prominent safety warning near the project overview, explaining the mains-voltage and EV charging risks of modifying the CP circuit. It also calls out that the design is not certified, is used at the builder's own risk, and points readers to the safety model and license for the fail-safe rationale and warranty disclaimer.
2026-09-04 Add EVSE enclosure photos
    Document the installed EVSE enclosure in the README with new reference photos for visual context and installation tracking.
2026-09-04 Document real EVSE validation
    Updated the project notes to record the specific Geely Jueclat EV charger model used for the successful live-vehicle bench test and clarify the validation details in the bench testing summary.
2026-09-04 Clarify control law, battery handling, and control page
    Update README copy to use "settling control law" instead of "step-limited", and replace references to "sim-mode web page" with the unified "control page". Add a note that home-battery discharge is excluded from computed surplus (meter downstream of battery). Expand the control-page description to explain it is used for live operation and includes reactive simulated grid scenarios for bench/night testing.
2026-09-04 Document ISR-safe CP clamp timing
    Updated the CP interceptor documentation to reflect the final ISR-safe clamp assertion path. The pre-assert delay still uses the hardware timer ISR, but the clamp is now described as being driven via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
2026-09-04 Fix Sungrow battery power sign
    Correct the Sungrow WiNet battery-power interpretation: register 13021 is already positive=charging and negative=discharging, so we no longer negate the raw value. This fixes the control page showing battery discharge during real charging and updates the project docs to match the verified hardware behavior.
    [grid_source_sungrow_winet.cpp]
2026-09-05 Add 24h power history chart
    Adds a fixed-size 5-minute rolling history buffer for target and grid power, exposes it via /api/history, and renders a client-side chart on the control page. The buffer lives in RAM only, resets on reboot, and keeps each browser session aligned to the same rolling 24h view without persisting per-sample telemetry.
    [config.h]
2026-09-05 Persist power history to LittleFS
    Add on-disk persistence for the 24h power-history ring. Defines HISTORY_FILE_PATH/MA GIC/VERSION in include/config.h and implement history_load_from_fs()/history_save_to_fs() in solar_control.cpp using LittleFS. The file stores a small header (magic, version, history_created) + the HistoryBucket array. Load runs at task start; save runs on bucket rollover (~5min). Failures (no FS, size/magic/version mismatch, partial read) are treated as "no history" and fall back to the zeroed in-memory buffer. Also add LittleFS/string.h includes.
    [config.h]
2026-09-05 Negate Sungrow battery power register read
    Fix handling of Sungrow WiNet-S battery power (reg 13021). The register is a standalone S16 with raw positive=discharging/negative=charging; negate the raw value so it matches the project's positive=charging convention (outBatteryW). Update source comment and CLAUDE.md to document the sign decision and the same-day verification/revert history. Change limited to src/grid_source_sungrow_winet.cpp and docs; sanity bounds and other logic unchanged.
    [grid_source_sungrow_winet.cpp]
2026-09-05 Add battery-data-valid guard for surplus exclusion
    Add an outBatteryDataValid flag to the GridDataSource read API and thread it through all callers and sources. Simulated sources return true; the Sungrow WiNet source now tracks last successful batter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
2026-09-06 Derive battery direction from register 13000, not 13021's sign
    Register 13021 is magnitude-only on this inverter: it reads positive
    while charging and positive while discharging alike, so it carries no
    direction of its own. The code negated it unconditionally, so the
    control page reported "discharging" always - correct by accident
    whenever it was checked against a real discharge, wrong every time the
    battery charged (reported during the 12am-6am grid-charge window).
    This also cost real charging. effectiveGridPowerW adds fmaxf(0,
    -batteryPowerW) back to the meter reading to exclude battery discharge
    from EV surplus; with the sign permanently negative it added the
    battery's *charge* power ins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
    [grid_source_sungrow_winet.cpp]
2026-09-06 Stop persisting zero-sample history buckets (blank chart after reboot)
    history_save_to_fs() ran immediately after a new 5-minute bucket was
    created and before its first sample was added, so the persisted file's
    newest bucket always held sample_count == 0. A reboot restored it, its
    window had already passed so it could never be filled, and
    build_history_json() then computed target_sum_w / 0 and printed
    "target_w":nan. NaN is not valid JSON, so JSON.parse() threw in the
    browser and the power history chart drew nothing - permanently, after
    any power cycle.
    An empty .catch(function(){}) on the fetch swallowed the parse error,
    leaving nothing in the console to diagnose it from.
    Persist only aft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
2026-09-06 Refresh the control page when the firmware changes
    The page shell is a PROGMEM constant served with no cache headers at all -
    Arduino WebServer's _prepareHeader emits only the status line, Content-Type,
    Content-Length and Connection. Browsers therefore fell back to heuristic
    freshness and could keep serving a cached PAGE_HTML indefinitely after an
    OTA push, leaving old JS driving a new /api/status with nothing on screen
    to say so.
    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
2026-09-06 Add a lagged/cloudy simulated grid source
    None of the existing simulated sources can reproduce the charge-current
    oscillation, which is why four clean bench stages never caught it. They
    all compute outWatts from the instantaneous currentDrawW, reflecting the
    commanded draw back perfectly and noise-free - exactly the case a gain-1
    deadbeat control law is unconditionally stable against.
    This source adds the two things reality has: a vehicle current ramp
    (480W/s, advanced on millis() deltas) and a meter transport delay (a
    2-poll FIFO, ~10s), plus deterministic cloud variation from two
    incommensurate sines. Deliberately not random() - a run before a change
    and a run after it have to be comparab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
2026-09-06 Damp the control loop against measurement lag
    The charge current oscillated, worst on cloudy days, because the loop was
    sitting exactly on the stability boundary rather than merely near it.
    compute_next_target_amps() applied deltaA = surplusW / V at gain exactly
    1.0, with no filtering anywhere between the Modbus read and the commanded
    amps. With one decision-period of unabsorbed lag the error recurrence is
    e[n+1] = e[n] - e[n-1], characteristic z^2 - z + 1 = 0, roots of
    magnitude exactly 1: an undamped ring with a period of six decisions.
    Everything real pushes past that one step - the meter/register cadence,
    the vehicle's own current ramp, and the poll being up to 5s stale at
    decision time.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
    [config.h]
2026-09-09 Clarify CP status labels
    Updated the dashboard/status text for CP duty states to match the actual hardware behavior. Active clamping is now described as the charger holding the target duty cycle, while standby is labeled as 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
